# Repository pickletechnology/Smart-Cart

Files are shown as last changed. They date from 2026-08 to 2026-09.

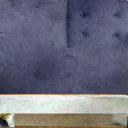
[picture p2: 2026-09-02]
labsim/assets/office2/conference_chair_blue.png

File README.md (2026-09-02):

# Smart Cart

An instrumented physics cart. An ESP32 reads acceleration, force, and wheel
rotation, and streams the combined state over Bluetooth LE to the Physics Cart
app at 20 Hz.

**Current version: V1** — the first complete build. Firmware and 3D-printable
hardware in this repository are all tagged `V1`.

## What's here

```
Smart-Cart/
├── firmware/
│   ├── README.md                       Board, libraries, flashing
│   └── PhysicsCart_V1/
│       └── PhysicsCart_V1.ino          Complete cart firmware
├── hardware/
│   ├── README.md                       Parts list and print settings
│   └── stl/
│       ├── Cart_Casing_8mm_Bearing_V1.stl   Main chassis      ×1
│       ├── Wheel_8mm_Bearing_V1.stl         Wheel             ×4
│       ├── Bearing_Casing_8mm_V1.stl        Bearing housing   ×4
│       └── Axle_8mm_V1.stl                  Axle              ×2
├── simulation/
│   ├── README.md                       Physics model and lab exercises
│   └── index.html                      Smart Cart Lab — browser simulation
├── game/
│   ├── README.md                       Game guide, assets, content pipeline
│   └── index.html                      Cart Blanche — physics adventure game
├── labsim/
│   ├── README.md                       Lab design, grading, assets
│   └── index.html                      The Physics Company — AP lab career
└── docs/
    ├── WIRING.md                       Pinout and sensor connections
    ├── CALIBRATION.md                  Every tunable constant, and how to set it
    └── BLE_PROTOCOL.md                 Service UUIDs and JSON payload format
```

## Simulation

[`simulation/index.html`](simulation/index.html) is **Smart Cart Lab**, a
browser-based 3D simulation of this cart for physics labs — open it in any
modern browser, no install or internet needed. Students run the classic
experiments (hanging mass, inclined track, fan force, bumper collisions,
friction) with live velocity/acceleration/force graphs, and the simulated
cart streams the same 20 Hz JSON lines as the real firmware, so a BLE client
can be developed against it before touching hardware. See
[`simulation/README.md`](simulation/README.md) for the physics model.

## Game

[`game/index.html`](game/index.html) is **Cart Blanche**, a physics adventure
game where the Smart Cart fights the Stationary Front across four worlds of
missions, kinetic-energy combat, and question gates — with XP levels, a shop,
and everything running on the same honest F = ma physics. Open it in any
browser; see [`game/README.md`](game/README.md).

## Lab career game

[`labsim/index.html`](labsim/index.html) is **The Physics Company**, an
AP® Physics 1 lab-career game: hired to certify the SC-01, students run six
real experiments (kinematics through rotation), read their own recorded
telemetry, and type numeric answers with units — checked against their run
within ±4%. Sensors are purchasable upgrades that unlock telemetry, labs pay
per verified answer, and a printable certification transcript records it all.
See [`labsim/README.md`](labsim/README.md).

## Hardware

| Component | Role | Interface |
|---|---|---|
| ESP32 | Controller, BLE peripheral | — |
| MPU-6050 | 3-axis accelerometer + gyroscope | I²C `0x68` |
| AS5600 | Magnetic rotary encoder (wheel angle / speed) | I²C `0x36` |
| HX711 + load cell | Force measurement | GPIO 19 (DOUT) / 18 (SCK) |

All printed parts are built around 8 mm bore bearings. Full pinout in
[`docs/WIRING.md`](docs/WIRING.md).

## Getting started

1. **Print the parts** — [`hardware/README.md`](hardware/README.md). Start with
   the axles and bearing casings to check your printer's tolerance against the
   8 mm bearings.
2. **Wire the electronics** — [`docs/WIRING.md`](docs/WIRING.md). Confirm both
   I²C devices appear on a scanner sketch before flashing.
3. **Flash the firmware** — [`firmware/README.md`](firmware/README.md).
4. **Calibrate** — [`docs/CALIBRATION.md`](docs/CALIBRATION.md). Do not skip
   this; two V1 constants ship with placeholder values.
5. **Connect** — the cart advertises as `PASCO_Cart`. Pair from the Physics Cart
   app, or write your own client against
   [`docs/BLE_PROTOCOL.md`](docs/BLE_PROTOCOL.md).

## Data output

20 Hz JSON notifications over BLE:

```json
{"t":12.34,"ax":0.012,"ay":-0.003,"az":0.998,"gx":0.1,"gy":-0.2,"gz":0.0,"f":0.482,"a":180.5,"r":42.3,"v":0.144}
```

Time (s), acceleration (g), angular rate (°/s), force (N), wheel angle (°),
wheel speed (RPM), and linear velocity (m/s).

## Known V1 issues

These are carried forward from the working build and left as-is in V1 so the
code in this repo matches the cart that was actually running. Each is worth
addressing in the next revision:

- **`WHEEL_DIAMETER_M` is 0.065 m, but the V1 wheel STL is 34 mm across.**
  Velocity scales directly with this constant, so it must be set to the wheel
  you actually built before velocity readings mean anything.
- **`FORCE_OFFSET` is 5396.799 N** and is added on top of the automatic
  boot-time `tare()`. It looks like a leftover from an earlier calibration run —
  `0.0` is the sensible default for a fresh build.
- **No serial output.** The header comment advertises Serial Monitor output, but
  the sketch never calls `Serial.begin()`. BLE is the only output in V1.
- **IMU offsets are all zero** — they are placeholders awaiting a real
  still-cart calibration run.

## Versioning

`V1` marks the first complete cart: firmware, chassis, wheels, bearing casings,
and axles as built. Future revisions get their own `V2` files rather than
overwriting these, so a printed cart can always be matched back to the firmware
it was built with.

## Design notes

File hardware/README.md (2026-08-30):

# Hardware — Smart Cart V1

3D-printable parts for the V1 physics cart. All models are binary STL, dimensioned
in millimetres, and built around **8 mm bore bearings**.

## Parts list

| File | Part | Bounding box (mm) | Triangles | Qty per cart |
|---|---|---|---|---|
| `stl/Cart_Casing_8mm_Bearing_V1.stl` | Main cart chassis / body | 165.0 × 31.8 × 90.0 | 11,164 | 1 |
| `stl/Wheel_8mm_Bearing_V1.stl` | Wheel with bearing seat | 34.0 × 13.3 × 34.0 | 1,192 | 4 |
| `stl/Bearing_Casing_8mm_V1.stl` | Bearing housing / retainer | 16.0 × 6.5 × 8.2 | 876 | 4 |
| `stl/Axle_8mm_V1.stl` | Axle | 4.5 × 41.6 × 4.5 | 842 | 2 |

## Non-printed hardware

- 8 mm bore ball bearings (one per wheel seat)
- Fasteners to suit the chassis mounting holes

## Suggested print settings

These are starting points, not measured-and-proven values — tune for your printer.

| Setting | Chassis | Wheels / bearing casings / axles |
|---|---|---|
| Material | PLA or PETG | PLA or PETG |
| Layer height | 0.20 mm | 0.16 mm |
| Walls | 3 | 3–4 |
| Infill | 20–25 % | 40 % |
| Supports | Only where overhangs require | Usually none |

Print the axles and bearing casings first — they are quick, and they confirm your
printer's tolerance against the 8 mm bearings before you commit to the ~4 hour
chassis print.

## Wheel diameter and the firmware

The V1 wheel STL measures **34 mm** across. The firmware's `WHEEL_DIAMETER_M`
constant currently reads `0.065` (65 mm). Velocity is derived from wheel
circumference, so this constant must match the wheel that is actually on the
cart — measure your printed-and-assembled wheel (including any tyre or grip
surface) and set it before trusting velocity data. See
[`../docs/CALIBRATION.md`](../docs/CALIBRATION.md).

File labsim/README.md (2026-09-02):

# The Physics Company

*Making Motion Happen™* — an AP® Physics 1 lab-career game built on the Smart
Cart simulation. You've been hired by The Physics Company's Field Test Division
to certify the **SC-01 Smart Cart** through seven laboratory evaluations. Run
the experiments, read **your own** recorded data, and type numeric answers
(with units) that are checked against that data.

**Run it:** open `labsim/index.html` in any browser — fully offline, all assets
embedded. Enter your name at hiring (it goes on your printable transcript).

## The shape of a day

- **Title screen** over a living city street (traffic, pedestrians, the TPC
  building), then a skippable **cinematic intro**: your character drives in,
  parks, walks to the front door — and sits down with **R. Fulcrum, Founder &
  Owner**, who explains exactly what you've signed up for (click / Space
  through the dialogue).
- **The lab floor is walkable** (WASD/arrows or click-to-walk, E to use):
  a test bench where the labs run, a workshop desk where the SC-01 gets
  modified, a mail terminal for Marla's memos (many take **replies** — pick
  one, she answers), an equipment wall, the Deep End tank, a records desk with
  your transcript, Engineer #7's taped-off desk… and your cot.
- **Bench setup, PC-Building-Simulator style**: every lab starts with a parts
  tray — click a part, click its glowing spot; **right-click a placed part**
  to take it back. **Drag to orbit the bench, scroll to zoom**; while setting
  up, the camera frames the whole track so every slot is in reach. Cart on
  the track, pulley clamped past the 10 m mark, hanging mass over the pulley,
  spring bumper, Cart B, the Deep End's tank/boom/test cylinder. Nothing runs
  until the bench is built, and Lab 01 walks first-timers through it step by
  step.
- **After each certified lab you clock out**: a night-time sleep cutscene ends
  the day (DAY N COMPLETE), the day counter and your clearance level tick up —
  and the lab wakes up a little more lived-in: coffee cups, takeout cartons
  and pizza boxes accumulate with every certification.
- **Engineer #7's notes are physical**: after each lab, one turns up somewhere
  on the lab floor. Walk to the glow and read it where it fell.

## How learning works here

- **Seven labs, one per AP Physics 1 unit** (fluids included, per the 2024+
  curriculum), each an in-depth multi-part worksheet (5 calculations + 1
  concept question, labeled like AP parts):
  1. **Kinematics** — Baseline Certification (position/time tables, x = ½at²;
     the boost pass is a hanging mass over the end pulley)
  2. **Dynamics & friction** — The Grip Department (μs = tan θ from a tilt
     test; μk from measured a on an incline; three real surfaces)
  3. **Energy** — The Conservation Audit (outdoor mountain range; mgh → ½mv²;
     % difference; work–energy on a gravel patch)
  4. **Momentum** — Impact Assessment (load-cell impulse ∫F dt vs Δp; elastic
     and perfectly inelastic collisions with Cart B)
  5. **Simple harmonic motion** — Resonance Division (period from zero
     crossings; k = 4π²m/T²; prediction with added mass)
  6. **Rotation** — The Spin Cycle (ω from real RPM; v = ωr; α; rolling
     without slipping)
  7. **Fluids** — The Deep End (weigh a test cylinder in air, submerge it on
     the load-cell winch; F_b = F_air − F_sub; ρ = F_b/Vg for water and brine
     from the student's own readings)
- **Answers are numeric + unit**, checked against the student's own run within
  ±4% (unit must be right too). Pay decays 100% → 70% → 40%: after two misses
  the worked solution appears, but the student must still enter the correct
  value to proceed. Nobody gets stuck; guessing still costs.
- **Experiment parameters are randomized per session** (friction coefficients,
  spring constants), so answers can't be shared — only methods can.
- **Sensors are upgrades**: the cart starts with just position (ruler +
  stopwatch). Buying the real V1 hardware unlocks capability — the AS5600
  encoder unlocks velocity telemetry, the MPU-6050 acceleration, the HX711
  load cell force/impulse — and each is required by a later lab (stipends in
  the story keep them affordable).
- **The transcript** (HQ → Transcript) is a printable/saveable certification
  record: name, hire date, per-lab score, attempt counts, and pay — evidence a
  teacher can check.

## The story

Corporate comedy with a mystery, told interactively: memos from Marla Joule
(Director of Cart Reliability, extremely fast in hallways — watch the
sidewalk) assign each lab and take replies; HR sends automated warnings about
naming company property; and physical notes from vanished Test Engineer #7
turn up on the lab floor after each certification… ending with a message from
the SC-01 itself (which also takes a reply). Days pass, clearance levels rise,
takeout accumulates, certificates fill the wall, and cosmetic upgrades
(shells, LED colors, accessories, office furniture) make your corner of the
company visibly yours. The finale is a warm one — listen to the LED.

## Assets

- **KayKit Block Bits**, **KayKit Furniture Bits**, and **KayKit City Bits**
  by Kay Lousberg (kaylousberg.com), CC0 — test-chamber blocks, surfaces
  (metal/sand/frost/gravel), furniture, and the city street, buildings and
  cars. Licenses in `assets/*/LICENSE.txt`.
- **OFFICE** low-poly pack (user-provided, converted from `.glb` via
  `tools/convert-glb.mjs`) — desks, chairs, computers, cabinets, coffee
  machine, water cooler and friends.
- **MountainRocks** voxel pack (user-provided) — the outdoor test range.
- The SC-01 itself is procedural, with sensor modules that visibly bolt on as
  you buy them; the characters (you, Marla, pedestrians) are procedural
  low-poly walkers.

`tools/build-assets.mjs` parses everything under `assets/` into compact mesh
data embedded between the `/*ASSETS_START*/` markers — drop in new `.obj`
files (with `atlas.png` for shared-atlas packs, or per-model `.png`) and
re-run it.

## Engine notes

Physics integrates at 240 Hz per lab-specific force model; telemetry records
at 60 Hz into the data table (0.5 s rows), charts, and an events line (slip
angle, impulse, contact time, zero crossings…). Question generators compute
accepted answers from the same recorded arrays the student reads, so the
numbers always agree with the screen. AP® is a trademark of the College
Board, which was not involved in and does not endorse this project.

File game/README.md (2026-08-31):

# Cart Blanche — the Smart Cart video game

*Physics, floor it.*

A single-file HTML5 physics adventure game starring **Newt**, a self-aware
Smart Cart, versus the **Stationary Front** — a union of grumpy lab equipment
sworn to bring all motion to a stop. Everything in the game runs on honest
physics, and every fight, gate, and upgrade teaches some of it.

**Run it:** open `game/index.html` in any modern browser. Fully offline —
Three.js and all 3D assets are embedded/vendored. Keyboard: ◀ ▶ thrust,
▼ brake, Esc pause, R restart. Touch controls appear on mobile.

## What's in the game

- **A walkable campus hub**: you play a lab tech on foot (WASD / drag to
  walk, Shift to run, E to interact) exploring a large open campus with
  Newt trundling along behind you. Four world portals, NPCs with physics
  gossip, Millie Volt's shop as a real building, and one-time collectible
  coins are scattered across the map. Menus (Missions/Shop buttons) remain
  as fast travel.
- **4 worlds × 5 missions** (20 total), each world tied to a physics topic:
  *Vector Valley* (kinematics), *Grindstone Gulch* (friction & inclines),
  *The Conservatory* (energy), *The Colliseum* (momentum) — each ending in a
  boss fight (Delta Vee, Big Mu, Grand Dame Potentia, General Standstill).
- **Real physics engine** (120 Hz): F = ma along the slope, gravity g·sinθ
  on hills, rolling friction, quadratic drag, ballistic flight off crests,
  mud (μ×14) and ice (μ×0.1) zones. The HUD telemetry strip — velocity,
  acceleration, force, kinetic energy — is the same set of quantities the
  real Smart Cart streams over BLE.
- **PVE with kinetic-energy combat**: every enemy wears its KE threshold in
  joules; you destroy it only if your live ½mv² beats that number when you
  ram, otherwise you bounce and lose battery. Turrets lob real parabolic
  projectiles. Bosses take multiple hits and enrage.
- **Question gates**: 48 multiple-choice physics questions (12 per topic,
  each bank independently re-derived and corrected by a verifier pass)
  block checkpoints; correct answers pay points, XP, and battery — and
  stack an **Overvolt streak** (+1 N thrust per first-try answer, up to
  +3 N, lost on a wrong answer). A **LETHAL glow** on the KE readout shows
  when your kinetic energy currently beats a nearby enemy's threshold.
- **Points, stars, and par scores** per mission; battery and time convert
  to bonus points at the finish.
- **Leveling**: XP from missions and questions; levels + beaten bosses
  unlock the next world.
- **Shop**: spend Joulies with Millie Volt on a stronger motor (thrust),
  slicker bearings (lower μ), a bigger battery (more health, but heavier —
  trade-offs are physics too), an impulse-damper shield, a coin magnet,
  and cosmetic car bodies.
- **Mission types**: reach, coin-collect, speed-window finishes, battles,
  and boss fights, over six procedural terrain profiles (seeded per mission,
  so a mission's track is always the same).
- Saves in `localStorage` (per browser). "Reset save" on the title screen.

## Assets

- **KayKit City Builder Bits 1.0** by Kay Lousberg (kaylousberg.com) — CC0.
  Buildings, cars (the player cart and several enemies/skins), streetlights,
  traffic lights, props. License copy in `assets/kaykit/LICENSE.txt`.
- **MagicaVoxel building models** (`assets/voxel/`) — uploaded pack of six
  voxel buildings used as skyline decoration.
- Everything else (terrain, gates, coins, effects, extra props) is generated
  procedurally in code.

### Asset pipeline

`tools/build-assets.mjs` parses every `.obj` under `assets/` into compact
quantized mesh data (positions ×1000, UVs ×10000, indexed, with bounding
boxes), base64-encodes the textures, and splices the result into
`index.html` between the `/*ASSETS_START*/ … /*ASSETS_END*/` markers.
To add more assets: drop `.obj` (+ texture) files into `assets/kaykit/`
(shared atlas) or `assets/voxel/` (per-model texture), run
`node game/tools/build-assets.mjs`, and reference the new mesh names in
`WORLD_ART`/`extraProp` in `index.html`.

## Content pipeline

The theme, mission set, enemy roster, shop economy, and question banks were
generated as structured JSON by a multi-agent workflow (three competing
creative directions judged and synthesized; question banks written per topic
then adversarially re-derived by an independent checker) and embedded at the
`/*__GAME_DATA__*/` marker. The game reads everything from that `DATA`
constant, so content can be regenerated or hand-edited without touching the
engine.

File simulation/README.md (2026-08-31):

# Smart Cart Lab — Physics Simulation

A browser-based simulation of the Smart Cart V1 for physics labs. Students set
up the same experiments they would run with the real cart — a hanging mass over
a pulley, an inclined track, a fan force, a collision with a spring bumper —
and read the same quantities the real hardware reports, in the same format.

**Run it:** open `index.html` in any modern browser. No build step, no server,
no internet connection required (Three.js is vendored in `vendor/`).

```
simulation/
├── index.html          The whole application (UI, physics, rendering)
├── vendor/
│   └── three.min.js    Three.js r128 (MIT), vendored for offline lab use
└── README.md           This file
```

## What it simulates

The apparatus is a track on a lab table, with:

| Element | Parameter | Range |
|---|---|---|
| Track length | table and camera resize with it | 0.60–2.00 m |
| Track incline | pivots at the pulley end, far end rises | 0–20° |
| Cart | mass (V1 printed cart ≈ 250 g default) | 150–1500 g |
| Hanging mass | string over an end pulley, classic modified Atwood | 0–300 g |
| Fan force | constant thrust along the track | ±1 N |
| Friction | single coefficient, kinetic + static (μₛ = 1.15 μₖ) | 0–0.30 |
| Spring bumper | at the pulley end, 900 N/m, tunable elasticity | 30–100 % |
| Initial push | initial velocity applied at t = 0 | ±1.2 m/s |

Five presets set these up as the classic experiments (Newton's second law,
inclined release, fan cart, bumper collision, static friction hold); every
slider stays live for custom setups.

### Equations of motion

Let `x` be the cart's distance from the pulley along the track and θ the
incline (the pulley end is the low end). With cart mass *m꜀*, hanging mass
*mₕ* and normal force *N = m꜀g cos θ*:

- **String taut** (coupled system, tension cannot be negative):
  `(m꜀ + mₕ) ẍ = F_fan + F_bumper − m꜀g sin θ − mₕg ∓ μₖN`
  and the tension the force sensor reads is `T = mₕ(g + ẍ)`.
- **String slack / no hanging mass:** the cart moves alone and the mass
  free-falls. When the cart re-tensions the string, the snap is resolved by
  momentum conservation along the string (both bodies jump to the common
  constraint velocity), and the jolt shows up on the simulated IMU.
- **Mass lands:** when the hanging mass reaches the floor the string goes
  slack — the classic "acceleration stops mid-run" feature of this lab.
- **Static friction** holds the cart whenever it is at rest and the net
  driving force is below μₛN (so a cart on a shallow incline genuinely
  does not move until tan θ exceeds μₛ).
- **Bumper:** a damped spring (`F = kΔx − cẋ`, k = 900 N/m); the damping
  is derived from the elasticity slider, and the contact force is what the
  hook force sensor reports (negative = compression), so students can see
  that a collision is a brief, large force and measure the impulse.

Integration is semi-implicit Euler at 240 Hz — four physics substeps per
sensor sample, so collisions and string snaps are resolved well below the
sensor timescale.

### The sensor pipeline mirrors the V1 firmware

The point of the app is that students practice on *instrument readings*, not
on idealized values, so the measurement chain from
`firmware/PhysicsCart_V1/PhysicsCart_V1.ino` is reproduced:

- Sensors sample at **60 Hz**; the BLE JSON line is emitted at **20 Hz** in
  the exact `snprintf` format and precision of the firmware
  (`{"t":…,"ax":…,…,"v":…}` — see `docs/BLE_PROTOCOL.md`).
- **IMU (MPU-6050):** reports *specific force* in g, so `az ≈ cos θ` at rest
  (≈ +1 g on the level — the firmware's calibration check) and `ax ≈ 0`
  during frictionless free roll, because an accelerometer measures proper
  acceleration. Bumper impacts ring the chassis at ~42 Hz. The cart's IMU
  x-axis points toward the pulley, matching how the cart is set on the track.
- **Wheel encoder (AS5600):** wheel angle wraps 0–360°, RPM goes through the
  firmware's 5-sample moving average and is forced to zero below 2 RPM, and
  reported velocity is `(RPM / 60) × π × d` — with **d = 34 mm**, the size the
  V1 wheel actually prints at (see "Known V1 issues" in the root README).
- **Load cell (HX711):** reads the hook — string tension positive, bumper
  compression negative, `FORCE_OFFSET = 0` (a freshly calibrated cart).
- **Noise toggle:** Gaussian sensor noise at realistic levels
  (σ ≈ 3 mg accel, 0.15 °/s gyro, 15 mN force, 0.8 RPM encoder jitter).
  Switch it off to compare against clean theory.

### Displays

- Live readout tiles: position, velocity, acceleration, hook force, wheel
  RPM, and the IMU's `az` (the "is the cart level?" sanity check).
- Three strip charts (10 s window): velocity, acceleration, hook force —
  plotting what the *sensors* report, like real DAQ software.
- A **BLE Notify console** streaming the exact 20 Hz JSON lines, so students
  can develop and test a client against `docs/BLE_PROTOCOL.md` behavior
  before touching hardware.
- **CSV export** (download or copy): 60 Hz samples with both the sensor
  readings and the true kinematic values side by side, for analysis in a
  spreadsheet — comparing the two *is* a good lab exercise.

### Rendering

Three.js with physically-based materials, one warm key light casting soft
shadows (2048² PCF), a cool hemisphere sky term for ambient, and ACES filmic
tone mapping. Scene units are metres and the geometry matches the build: a
34 mm wheel is a 34 mm wheel on screen.

## Suggested lab exercises

1. **Newton's second law** — vary the hanging mass, measure the slope of the
   velocity trace, compare with `a = mₕg / (m꜀ + mₕ)`. Explain the kink in
   the trace when the mass hits the floor.
2. **g from an incline** — release from rest at several angles, plot `a`
   against `sin θ`, extract g from the slope and μ from the intercept.
3. **Proper acceleration** — explain why `ax` reads ≈ 0 while the cart rolls
   freely downhill but `−sin θ` when it is held still.
4. **Impulse–momentum** — integrate the force spike of a bumper collision
   (export CSV) and compare with the measured Δv, at several elasticities.
5. **Static vs kinetic friction** — with μ = 0.15, raise the incline slowly
   until the cart breaks away; compare the break-away angle with arctan μₛ.

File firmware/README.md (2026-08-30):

# Firmware — Smart Cart V1

`PhysicsCart_V1/PhysicsCart_V1.ino` — the complete cart firmware. Reads the
MPU-6050, HX711 load cell, and AS5600 encoder, and streams the combined state
over BLE as JSON.

## Board

ESP32 (any dev board with BLE). Select it in **Tools → Board** before compiling;
the sketch uses the ESP32 BLE stack (`BLEDevice.h` and friends), which ships with
the ESP32 Arduino core.

## Library dependencies

Install through **Sketch → Include Library → Manage Libraries…**:

| Library | Used for |
|---|---|
| `HX711` (bogde) | Load cell amplifier |
| `AS5600` (RobTillaart) | Magnetic rotary encoder |

`Wire.h` and the `BLE*` headers come from the ESP32 core — nothing to install.

## Flashing

1. Install the ESP32 board support package (Boards Manager URL:
   `https://raw.githubusercontent.com/espressif/arduino-esp32/gh-pages/package_esp32_index.json`).
2. Open `PhysicsCart_V1/PhysicsCart_V1.ino`. The folder name must keep matching
   the sketch name — Arduino requires it.
3. Select your ESP32 board and port, then Upload.

## Loop timing

| Task | Rate | Constant |
|---|---|---|
| Sensor sampling | 60 Hz | `SENSOR_INTERVAL_US = 16667` |
| BLE notification | 20 Hz | `BLE_INTERVAL_MS = 50` |

## Before you trust the data

Work through [`../docs/CALIBRATION.md`](../docs/CALIBRATION.md). Two constants in
particular ship with values that will not be right for your build:
`WHEEL_DIAMETER_M` (65 mm, against a 34 mm V1 wheel STL) and `FORCE_OFFSET`
(5396.799 N, on top of an automatic boot-time tare).

## Output

BLE JSON at 20 Hz — see [`../docs/BLE_PROTOCOL.md`](../docs/BLE_PROTOCOL.md) for
the field-by-field payload description.

Note that the header comment mentions Serial Monitor output, but this version
does not call `Serial.begin()` or print anything. BLE is the only output path in
V1. Adding serial logging is a natural V1.1 change.

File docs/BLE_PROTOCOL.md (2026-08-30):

# BLE Protocol — Smart Cart V1

## Advertising

| Property | Value |
|---|---|
| Device name | `PASCO_Cart` |
| Service UUID | `4fafc201-1fb5-459e-8fcc-c5c9c331914b` |
| Characteristic UUID | `beb5483e-36e1-4688-b7f5-ea07361b26a8` |
| Characteristic properties | `READ`, `NOTIFY` (with a `0x2902` CCCD descriptor) |

The name `PASCO_Cart` is what the Physics Cart app scans for — changing it in the
firmware means the app will no longer find the cart.

## Data flow

- Sensors are sampled at **60 Hz** (`SENSOR_INTERVAL_US = 16667`).
- Notifications are sent at **20 Hz** (`BLE_INTERVAL_MS = 50`), only while a
  central is connected.
- On disconnect the firmware waits 500 ms and restarts advertising, so a client
  can reconnect without power-cycling the cart.

## Payload

Each notification is a UTF-8 JSON object, written into a 220-byte buffer:

```json
{"t":12.34,"ax":0.012,"ay":-0.003,"az":0.998,"gx":0.1,"gy":-0.2,"gz":0.0,"f":5396.799,"a":180.5,"r":42.3,"v":0.144}
```

| Key | Quantity | Unit | Notes |
|---|---|---|---|
| `t` | Time since boot | s | 2 decimal places |
| `ax` | Acceleration X | g | ±2 g range (16384 LSB/g) |
| `ay` | Acceleration Y | g | |
| `az` | Acceleration Z | g | Not offset-corrected — carries the 1 g gravity term |
| `gx` | Angular rate X | °/s | ±250 °/s range (131 LSB/°/s) |
| `gy` | Angular rate Y | °/s | |
| `gz` | Angular rate Z | °/s | |
| `f` | Force | N | Load cell, includes `FORCE_OFFSET` |
| `a` | Wheel angle | ° | AS5600, 0–360 |
| `r` | Wheel speed | RPM | 5-sample moving average; forced to 0 below 2 RPM |
| `v` | Linear velocity | m/s | Derived: `(RPM / 60) × wheel circumference` |

Acceleration is reported in **g**, not m/s² — multiply by 9.81 on the client if
you want SI units.

## Writing a client

1. Scan for `PASCO_Cart` or filter on the service UUID.
2. Connect, discover the service, and subscribe to notifications on the
   characteristic (write `0x0001` to its CCCD).
3. Parse each notification as JSON. Expect ~20 messages per second.

There are no writable characteristics in V1 — the cart is send-only. Taring,
calibration, and zeroing all happen in firmware at boot.

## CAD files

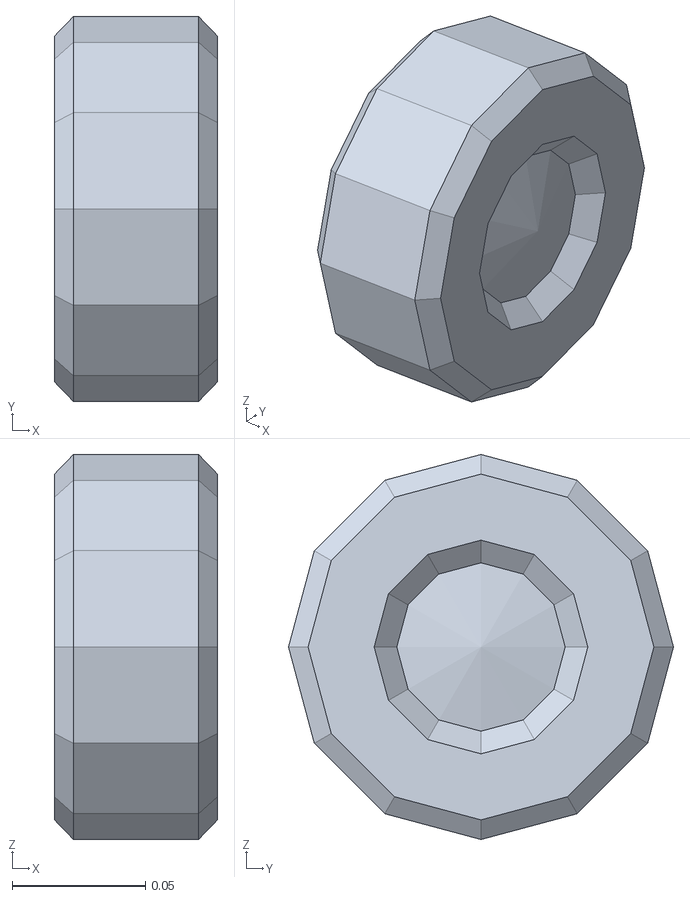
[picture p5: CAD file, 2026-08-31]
game/assets/kaykit/car_taxi_wheel_rear_left.obj
0.0612 x 0.145 x 0.145

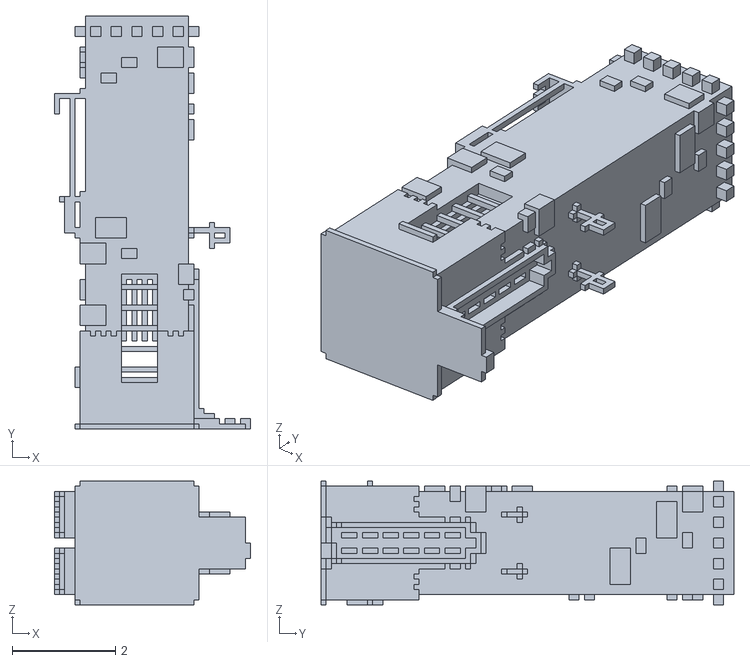
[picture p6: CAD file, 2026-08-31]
game/assets/voxel/TallBuilding03.obj
3.80 x 8.00 x 2.40

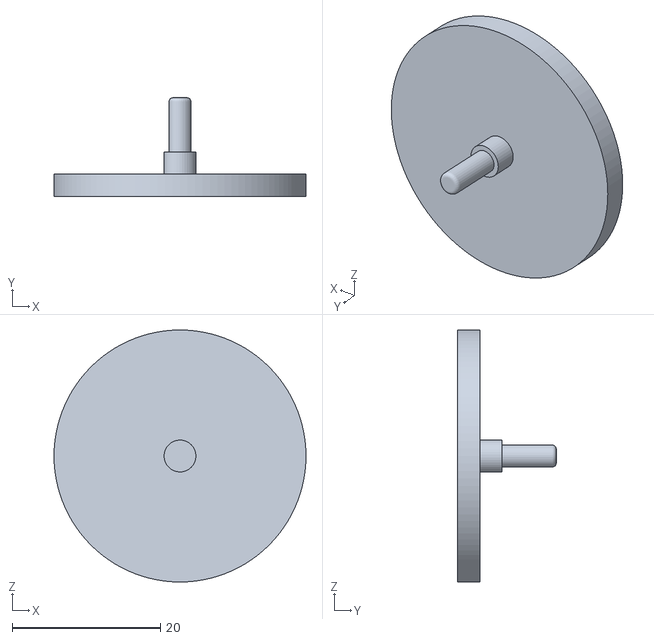
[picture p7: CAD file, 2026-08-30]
hardware/stl/Wheel_8mm_Bearing_V1.stl
34.0 x 13.3 x 34.0

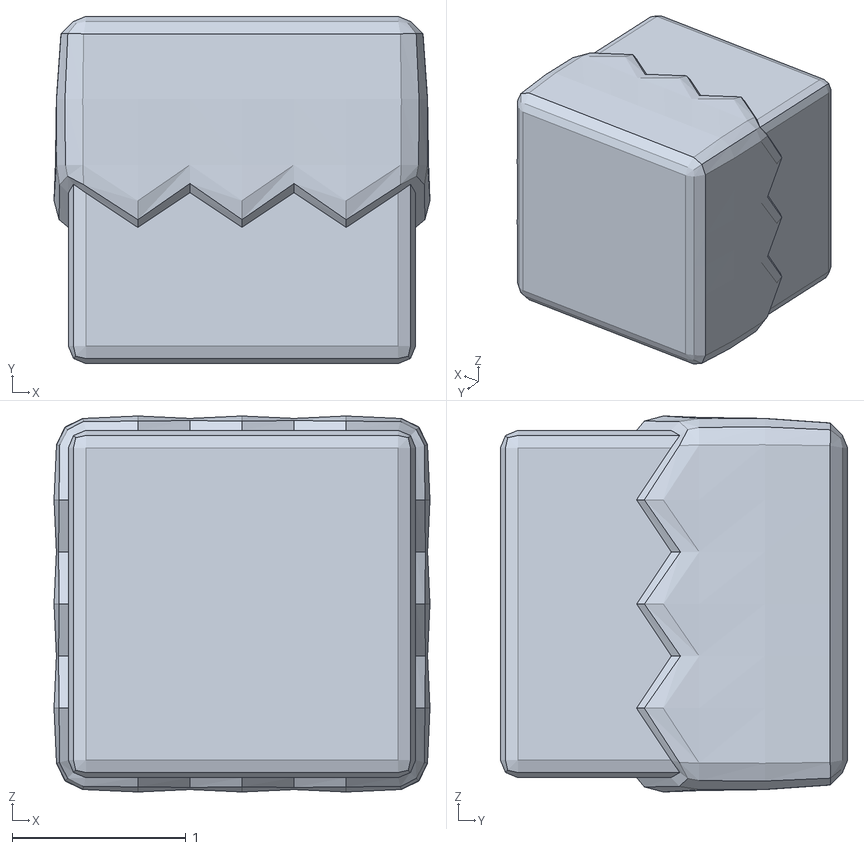
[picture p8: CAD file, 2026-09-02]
labsim/assets/blockbits/tree.obj
2.17 x 2.00 x 2.17

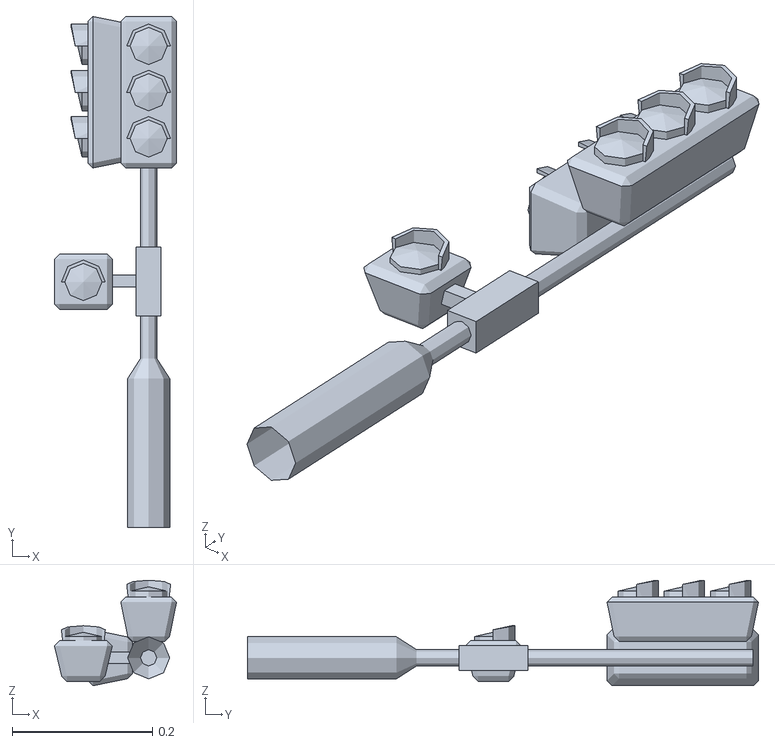
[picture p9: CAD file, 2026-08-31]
labsim/assets/city/trafficlight_A.obj
0.174 x 0.729 x 0.151

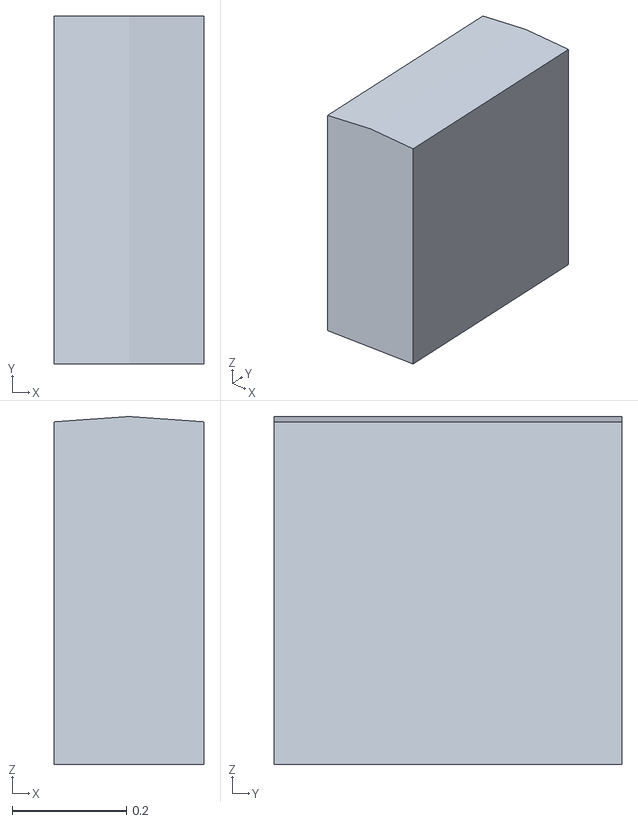
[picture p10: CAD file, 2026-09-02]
labsim/assets/computer/computer_tower.obj
0.262 x 0.609 x 0.609

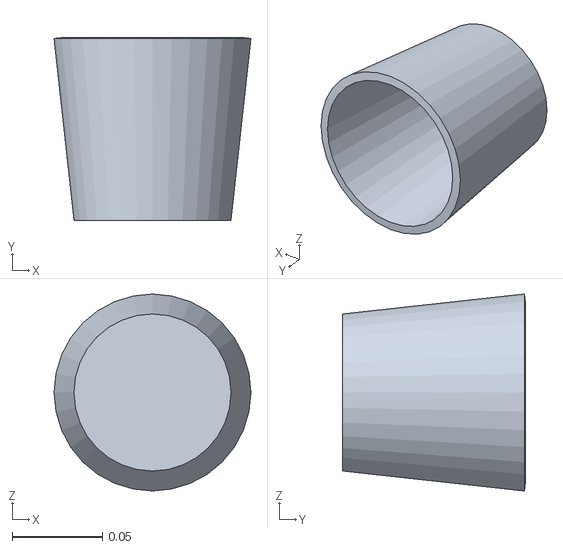
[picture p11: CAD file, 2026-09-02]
labsim/assets/deskpack/pencil_holder.obj
0.109 x 0.102 x 0.109

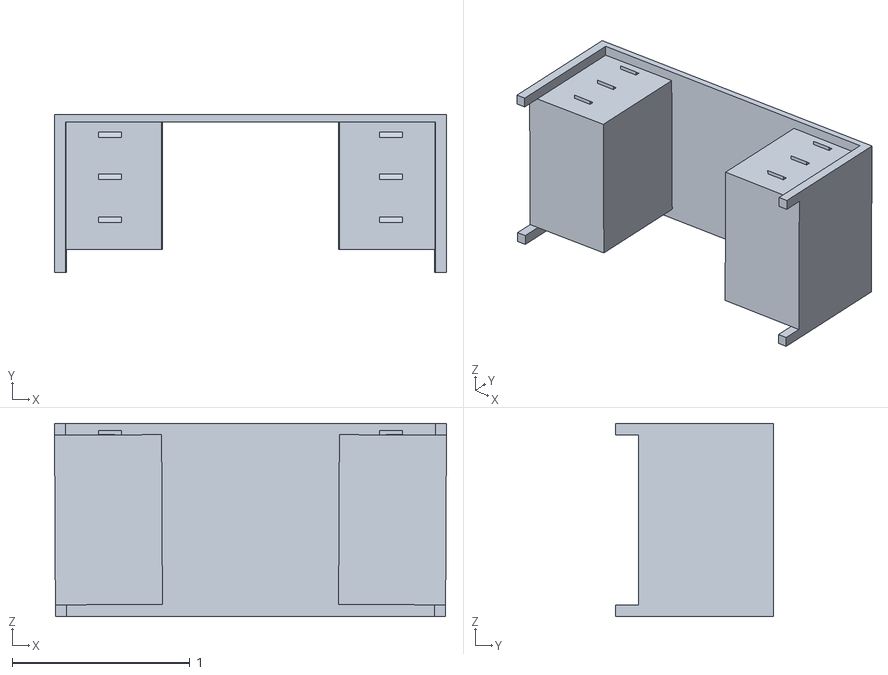
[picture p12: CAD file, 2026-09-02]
labsim/assets/desks1/desk1.obj
2.21 x 0.891 x 1.09

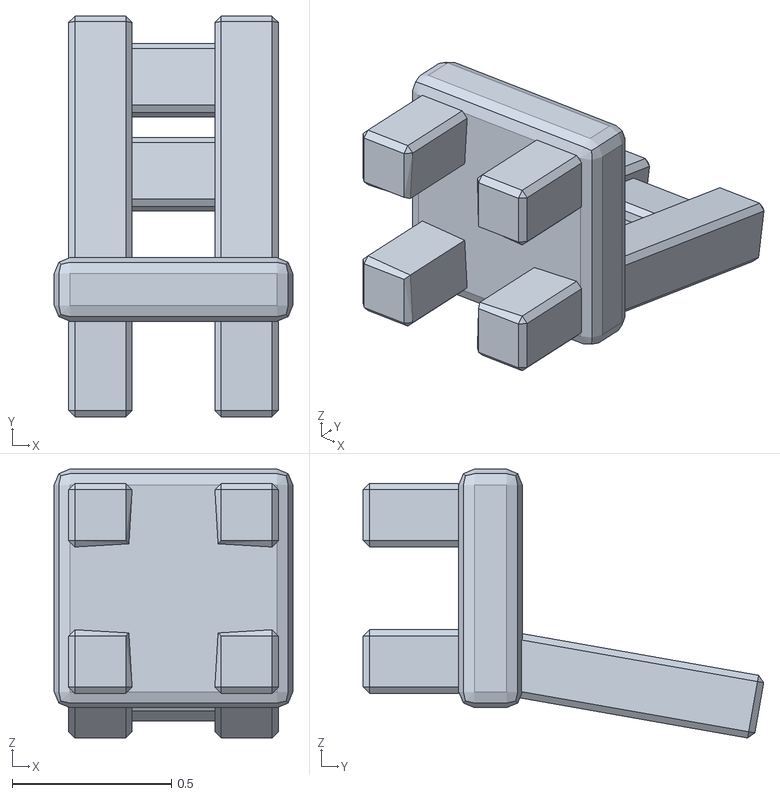
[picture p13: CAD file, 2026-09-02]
labsim/assets/furniture/chair_A.obj
0.75 x 1.26 x 0.845

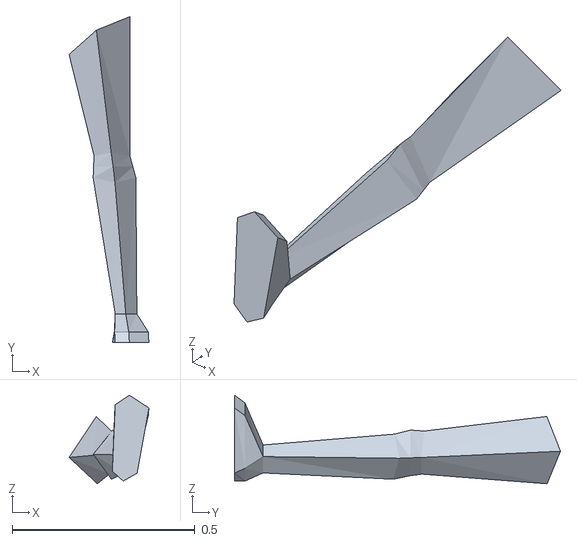
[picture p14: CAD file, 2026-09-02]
labsim/assets/human/h_legR.obj
0.219 x 0.893 x 0.243

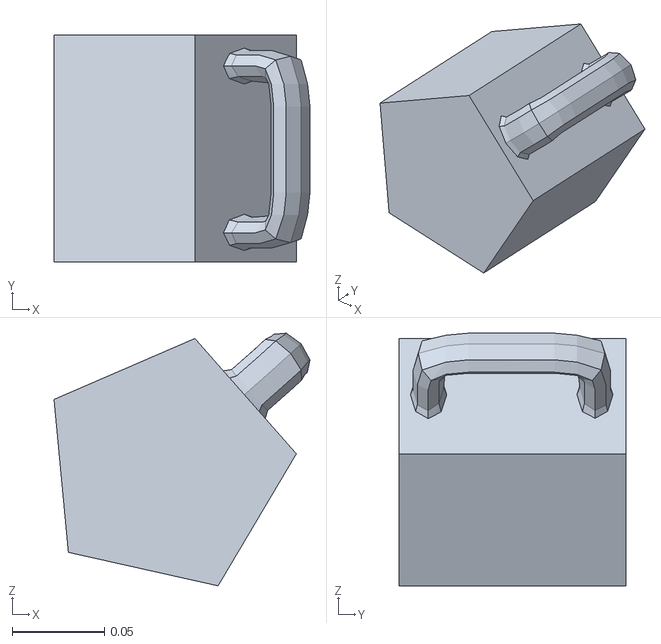
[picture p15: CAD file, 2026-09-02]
labsim/assets/office2/mug.obj
0.139 x 0.123 x 0.137

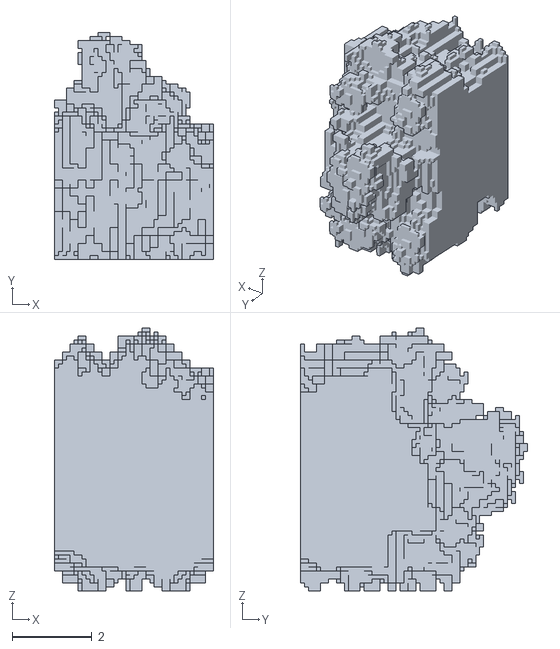
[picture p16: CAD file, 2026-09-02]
labsim/assets/rocks/MountainRocks-5.obj
4.00 x 5.70 x 6.60

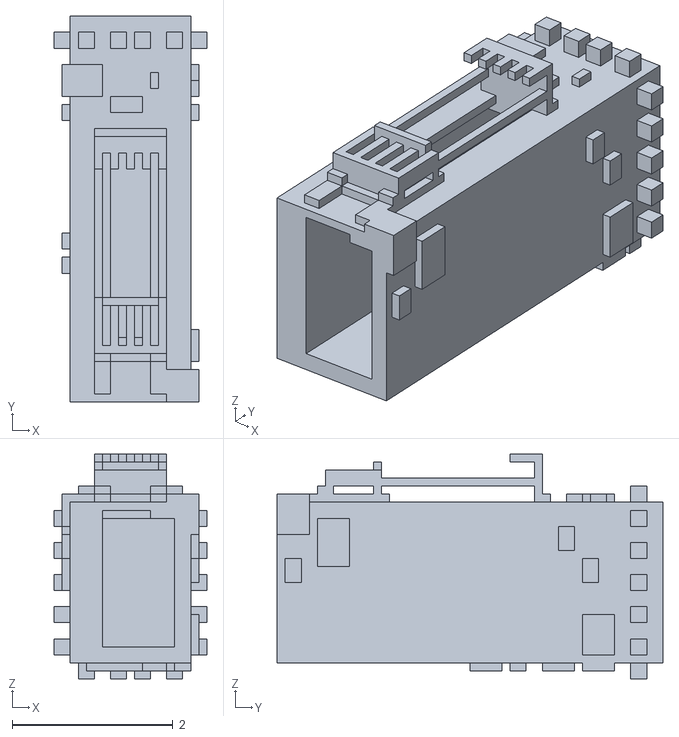
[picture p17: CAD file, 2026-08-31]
game/assets/voxel/TinyBuilding01.obj
1.90 x 4.80 x 2.80

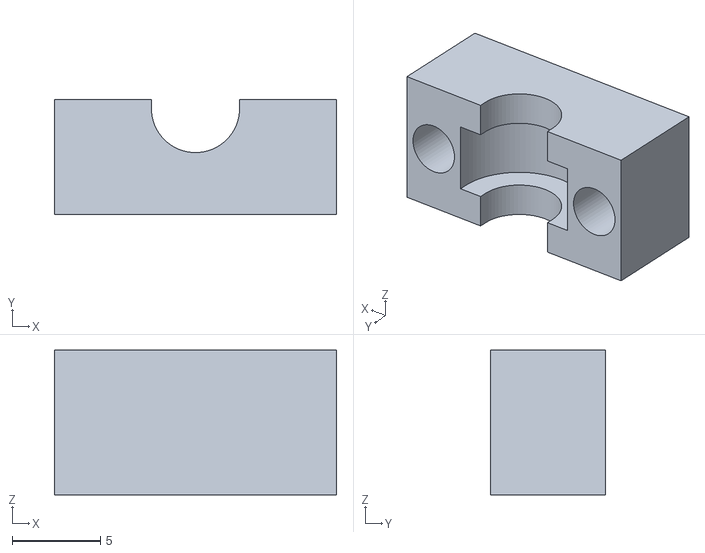
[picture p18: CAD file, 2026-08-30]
hardware/stl/Bearing_Casing_8mm_V1.stl
16.0 x 6.50 x 8.20

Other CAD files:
game/assets/kaykit/car_police_wheel_front_right.obj
labsim/assets/blockbits/colored_block_yellow.obj
labsim/assets/city/road_straight.obj
labsim/assets/computer/computer_keyboard.obj
game/assets/kaykit/box_A.obj
game/assets/kaykit/car_hatchback_wheel_front_left.obj
game/assets/kaykit/car_hatchback_wheel_front_right.obj
game/assets/kaykit/car_hatchback_wheel_rear_left.obj
game/assets/kaykit/car_hatchback_wheel_rear_right.obj
game/assets/kaykit/car_police_wheel_front_left.obj
game/assets/kaykit/car_police_wheel_rear_left.obj
game/assets/kaykit/car_police_wheel_rear_right.obj
game/assets/kaykit/car_stationwagon_wheel_front_left.obj
game/assets/kaykit/car_stationwagon_wheel_front_right.obj
game/assets/kaykit/car_stationwagon_wheel_rear_left.obj
game/assets/kaykit/car_stationwagon_wheel_rear_right.obj
game/assets/kaykit/car_taxi_wheel_front_left.obj
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

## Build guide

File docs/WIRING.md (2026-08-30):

# Wiring — Smart Cart V1

The firmware targets an **ESP32** (BLE + two hardware I²C-capable pins). Pin
assignments below are taken directly from `firmware/PhysicsCart_V1/PhysicsCart_V1.ino`.

## I²C bus (shared)

`Wire.begin(21, 22)` at 400 kHz.

| Signal | ESP32 pin |
|---|---|
| SDA | GPIO 21 |
| SCL | GPIO 22 |

Two devices share this bus:

| Device | Address | Purpose |
|---|---|---|
| MPU-6050 | `0x68` | 3-axis accelerometer + 3-axis gyroscope |
| AS5600 | `0x36` (fixed) | Magnetic rotary encoder — wheel angle and angular speed |

Both need 3.3 V and ground. The AS5600 breakout usually carries its own pull-ups;
if you have pull-ups on both boards the bus may still work, but drop one set if
you see I²C errors.

## HX711 load cell amplifier

| Signal | ESP32 pin |
|---|---|
| DOUT | GPIO 19 |
| SCK  | GPIO 18 |
| VCC  | 3.3 V (or 5 V if your board is 5 V-tolerant on data lines) |
| GND  | GND |

The load cell itself wires to the HX711 in the usual bridge arrangement
(E+/E−/A+/A−). Colour codes vary by cell — check your load cell's datasheet
rather than assuming.

## AS5600 magnet

The AS5600 reads a **diametrically magnetised** magnet mounted on the axle end,
centred over the chip and typically 0.5–3 mm away. `encoder.begin(4)` sets the
direction-control pin to GPIO 4. If your breakout has no DIR pin, tie it as the
board documents; a reversed reading shows up as negative RPM for forward motion.

## Power

Any supply that gives the ESP32 a clean 3.3 V rail. The HX711 is the noise-
sensitive part of this circuit — keep its wiring short, away from motor or
battery leads, and grounded to the same point as the ESP32.

## Quick check

With everything wired and powered, an I²C scanner sketch should report `0x68`
and `0x36`. If either is missing, fix that before flashing the cart firmware.

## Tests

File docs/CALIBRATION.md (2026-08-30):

# Calibration — Smart Cart V1

Every constant here lives at the top of
`firmware/PhysicsCart_V1/PhysicsCart_V1.ino`. Recalibrate after any mechanical
change — a new load cell, a reprinted wheel, a remounted sensor.

## 1. Wheel diameter — `WHEEL_DIAMETER_M`

```cpp
const float WHEEL_DIAMETER_M = 0.065;  // metres
```

Velocity is computed as `(RPM / 60) × π × WHEEL_DIAMETER_M`, so an error here
scales every velocity reading proportionally.

The V1 wheel STL measures **34 mm** (0.034 m) across, while the constant is set
to 65 mm. Measure the wheel you actually printed and assembled — with any tyre,
o-ring, or grip surface fitted, since that is what contacts the track — and set
the constant to that value in metres. Sanity-check by rolling the cart a
measured 1.000 m and confirming the integrated velocity lands near 1 m.

## 2. Load cell — `CALIBRATION_FACTOR`

```cpp
const float CALIBRATION_FACTOR = -33.0;  // raw units per gram
```

1. Flash a sketch that prints `scale.get_units()` with the scale factor set to `1.0`.
2. With nothing on the cell, note the raw reading, then call `tare()`.
3. Place a known mass (a calibration weight, or anything you have measured on an
   accurate scale) and note the new raw reading.
4. `CALIBRATION_FACTOR = (loaded_raw − tared_raw) / known_mass_in_grams`.
5. Keep the sign — negative simply means the cell is wired or loaded in the
   opposite sense, which is fine.

Verify with a second, different mass. The reading should be within a few percent.

## 3. Force zero — `FORCE_OFFSET`

```cpp
const float FORCE_OFFSET = 5396.799;  // newtons
```

This is added to every force reading:
`force_N = (grams / 1000 × 9.81) + FORCE_OFFSET`.

Note that the firmware already calls `scale.tare(20)` at boot, which zeroes the
cell in hardware. A non-zero `FORCE_OFFSET` on top of that shifts every reported
force by a constant — the value above is large enough that it dominates the
signal, so it is almost certainly a leftover from an earlier calibration run.
**Unless you know why you need it, set it to `0.0`.** If you do need an offset,
derive it as the average steady-state force reported with the cart at rest and
unloaded, negated.

## 4. IMU offsets — `ACCEL_*_OFFSET`, `GYRO_*_OFFSET`

```cpp
const float ACCEL_X_OFFSET = 0.0;
const float ACCEL_Y_OFFSET = 0.0;
const float GYRO_X_OFFSET  = 0.0;
const float GYRO_Y_OFFSET  = 0.0;
const float GYRO_Z_OFFSET  = 0.0;
```

With the cart level and completely still, log `ax`, `ay`, `gx`, `gy`, `gz` for
about 10 seconds and average each. Those averages are your offsets — the
firmware subtracts them.

`accelZ` is deliberately **not** offset-corrected: it should read ≈ +1.0 g at
rest, since it carries gravity. Use that as your check that the IMU is level and
scaled correctly.

## 5. Noise floor — `RPM_THRESHOLD` and `NUM_SAMPLES`

```cpp
const float RPM_THRESHOLD = 2.0;   // below this, RPM is reported as 0
const int   NUM_SAMPLES   = 5;     // moving-average window
```

Encoder jitter makes a stationary wheel report small non-zero RPM. Watch the
reported RPM with the cart at rest and set `RPM_THRESHOLD` just above the
observed noise. Raising `NUM_SAMPLES` smooths the signal but adds lag — at 60 Hz
sampling, 5 samples is about 83 ms of averaging.

## Calibration record

Fill this in for your build so the numbers are not lost between sessions.

| Constant | V1 default | Your value | Date | Notes |
|---|---|---|---|---|
| `WHEEL_DIAMETER_M` | 0.065 | | | Measure the assembled wheel |
| `CALIBRATION_FACTOR` | −33.0 | | | |
| `FORCE_OFFSET` | 5396.799 | | | Consider 0.0 |
| `ACCEL_X_OFFSET` | 0.0 | | | |
| `ACCEL_Y_OFFSET` | 0.0 | | | |
| `GYRO_X_OFFSET` | 0.0 | | | |
| `GYRO_Y_OFFSET` | 0.0 | | | |
| `GYRO_Z_OFFSET` | 0.0 | | | |
| `RPM_THRESHOLD` | 2.0 | | | |

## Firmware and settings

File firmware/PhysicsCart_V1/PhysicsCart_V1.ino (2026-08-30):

// ════════════════════════
// Physics Cart V1 — Complete Firmware
// Sensors: MPU-6050, HX711, AS5600
// Output:  Bluetooth BLE + Serial Monitor
// ════════════════════════

#include <Wire.h>
#include <HX711.h>
#include <AS5600.h>
#include <BLEDevice.h>
#include <BLEServer.h>
#include <BLEUtils.h>
#include <BLE2902.h>

// ── Pin Definitions ──
#define HX711_DOUT  19
#define HX711_SCK   18
const int MPU_ADDR = 0x68;

// ── Calibration Constants (update after calibrating) ──
const float CALIBRATION_FACTOR  = -33.0;     // raw units per gram
const float FORCE_OFFSET        = 5396.799;  // zero offset (N)
const float GRAVITY             = 9.81;
const float WHEEL_DIAMETER_M    = 0.065;     // measure your wheel (m)
const float WHEEL_CIRCUMFERENCE = WHEEL_DIAMETER_M * 3.14159;
const float RPM_THRESHOLD       = 2.0;       // below this = stopped
const int   NUM_SAMPLES         = 5;         // RPM averaging window

const float ACCEL_X_OFFSET = 0.0;
const float ACCEL_Y_OFFSET = 0.0;
const float GYRO_X_OFFSET  = 0.0;
const float GYRO_Y_OFFSET  = 0.0;
const float GYRO_Z_OFFSET  = 0.0;

// ── BLE UUIDs ──
#define SERVICE_UUID        "4fafc201-1fb5-459e-8fcc-c5c9c331914b"
#define CHARACTERISTIC_UUID "beb5483e-36e1-4688-b7f5-ea07361b26a8"

BLECharacteristic *pCharacteristic;
BLEServer         *pServer;
bool deviceConnected = false;
bool wasConnected    = false;

class MyCallbacks : public BLEServerCallbacks {
  void onConnect(BLEServer *pServer)    { deviceConnected = true; }
  void onDisconnect(BLEServer *pServer) { deviceConnected = false; }
};

const unsigned long SENSOR_INTERVAL_US = 16667; // 60Hz
const unsigned long BLE_INTERVAL_MS    = 50;    // 20Hz
unsigned long lastSensorUpdate = 0;
unsigned long lastBLEUpdate    = 0;
unsigned long startTime;

HX711  scale;
AS5600 encoder;
float rpmSamples[NUM_SAMPLES] = {0};
int   sampleIndex = 0;

float accelX, accelY, accelZ;
float gyroX, gyroY, gyroZ;
float lastNewtons = 0;
float angle, rpm, velocity, seconds;

void setup() {
  Wire.begin(21, 22);
  Wire.setClock(400000);
  delay(1000);
  Wire.beginTransmission(MPU_ADDR);
  Wire.write(0x6B); Wire.write(0);
  Wire.endTransmission(true);
  scale.begin(HX711_DOUT, HX711_SCK);
  delay(2000);
  if (scale.is_ready()) { scale.set_scale(CALIBRATION_FACTOR); scale.tare(20); }
  encoder.begin(4);
  BLEDevice::init("PASCO_Cart");   // matches the Physics Cart App
  pServer = BLEDevice::createServer();
  pServer->setCallbacks(new MyCallbacks());
  BLEService *pService = pServer->createService(SERVICE_UUID);
  pCharacteristic = pService->createCharacteristic(
    CHARACTERISTIC_UUID,
    BLECharacteristic::PROPERTY_READ | BLECharacteristic::PROPERTY_NOTIFY);
  pCharacteristic->addDescriptor(new BLE2902());
  pService->start();
  BLEAdvertising *pAdv = pServer->getAdvertising();
  pAdv->addServiceUUID(SERVICE_UUID);
  pAdv->setScanResponse(true);
  pAdv->setMinPreferred(0x06);
  pAdv->start();
  startTime = millis();
}

void readSensors() {
  Wire.beginTransmission(MPU_ADDR);
  Wire.write(0x3B); Wire.endTransmission(false);
  Wire.requestFrom(MPU_ADDR, 14, true);
  int16_t ax = Wire.read() << 8 | Wire.read();
  int16_t ay = Wire.read() << 8 | Wire.read();
  int16_t az = Wire.read() << 8 | Wire.read();
  Wire.read(); Wire.read();
  int16_t gx = Wire.read() << 8 | Wire.read();
  int16_t gy = Wire.read() << 8 | Wire.read();
  int16_t gz = Wire.read() << 8 | Wire.read();
  accelX = (ax / 16384.0) - ACCEL_X_OFFSET;
  accelY = (ay / 16384.0) - ACCEL_Y_OFFSET;
  accelZ =  az / 16384.0;
  gyroX  = (gx / 131.0) - GYRO_X_OFFSET;
  gyroY  = (gy / 131.0) - GYRO_Y_OFFSET;
  gyroZ  = (gz / 131.0) - GYRO_Z_OFFSET;
  if (scale.is_ready()) {
    float grams = scale.get_units(1);
    lastNewtons = (grams / 1000.0 * GRAVITY) + FORCE_OFFSET;
  }
  angle = encoder.readAngle() * 0.0879;
  float rawRPM = encoder.getAngularSpeed();
  rpmSamples[sampleIndex] = rawRPM;
  sampleIndex = (sampleIndex + 1) % NUM_SAMPLES;
  float avgRPM = 0;
  for (int i = 0; i < NUM_SAMPLES; i++) avgRPM += rpmSamples[i];
  avgRPM /= NUM_SAMPLES;
  rpm      = (abs(avgRPM) < RPM_THRESHOLD) ? 0.0 : avgRPM;
  velocity = (rpm / 60.0) * WHEEL_CIRCUMFERENCE;
  seconds  = (millis() - startTime) / 1000.0;
}

void loop() {
  if (!deviceConnected && wasConnected) {
    delay(500); pServer->getAdvertising()->start(); wasConnected = false;
  }
  if (deviceConnected) wasConnected = true;
  unsigned long nowUS = micros(), nowMS = millis();
  if (nowUS - lastSensorUpdate >= SENSOR_INTERVAL_US) {
    lastSensorUpdate = nowUS; readSensors();
  }
  if (deviceConnected && (nowMS - lastBLEUpdate >= BLE_INTERVAL_MS)) {
    lastBLEUpdate = nowMS;
    char json[220];
    snprintf(json, sizeof(json),
      "{\"t\":%.2f,\"ax\":%.3f,\"ay\":%.3f,\"az\":%.3f,\"gx\":%.1f,\"gy\":%.1f,\"gz\":%.1f,\"f\":%.3f,\"a\":%.1f,\"r\":%.1f,\"v\":%.3f}",
      seconds, accelX, accelY, accelZ, gyroX, gyroY, gyroZ,
      lastNewtons, angle, rpm, velocity);
    pCharacteristic->setValue(json);
    pCharacteristic->notify();
  }
}

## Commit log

2026-08-30 Add Smart Cart V1: firmware, 3D-printable parts, and docs
    First complete version of the instrumented physics cart.
    Firmware (firmware/PhysicsCart_V1/): ESP32 sketch reading MPU-6050,
    HX711 load cell, and AS5600 encoder, streaming JSON over BLE at 20 Hz
    with 60 Hz sensor sampling.
    Hardware (hardware/stl/): four printable parts built around 8 mm bore
    bearings — chassis, wheel, bearing casing, and axle — all named V1.
    Docs (docs/): pinout and sensor connections, a calibration procedure
    covering every tunable constant, and the BLE service/payload spec.
    Known V1 issues are recorded in the README rather than patched, so the
    code here matches the cart as actually built: WHEEL_DIAMETER_M is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
    [Axle_8mm_V1.stl, Bearing_Casing_8mm_V1.stl, Cart_Casing_8mm_Bearing_V1.stl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]
2026-08-31 Add Smart Cart Lab: browser physics simulation for labs
    A self-contained 3D simulation (simulation/index.html) of the V1 cart:
    modified-Atwood hanging mass, inclined track, fan force, static/kinetic
    friction and spring-bumper collisions, integrated at 240 Hz. The sensor
    pipeline mirrors the firmware — 60 Hz sampling, 20 Hz BLE-format JSON
    stream, 5-sample RPM average with 2 RPM cutoff, IMU reporting specific
    force in g, 34 mm wheel — with live velocity/acceleration/force charts,
    readout tiles, sensor-noise toggle and CSV export. Three.js r128 is
    vendored so the app runs offline in a lab.
    Claude-Session: https://claude.ai/code/sessio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
2026-08-31 Make track length adjustable (0.6-2.0 m)
    New Track length slider. Physics bounds, the far end-stop, levelling
    feet, table size, start-position slider range and camera framing all
    follow the chosen length; changing it mid-run restarts the experiment,
    like swapping the physical track. The fan-cart preset now uses the
    full 2 m track.
    Claude-Session: https://claude.ai/code/session_01Cjnu12mGB59BoubPXChxjT
2026-08-31 Add a Reset values button
    Restores the selected preset's slider values, or the app defaults when
    on a custom setup; also re-enables sensor noise. Distinct from Reset,
    which only rewinds the run.
    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
2026-08-31 Add Cart Blanche: physics adventure game with missions, PVE and shop
    A single-file 3D game (game/index.html) built on the Smart Cart theme:
    20 missions across 4 physics worlds, kinetic-energy ram combat with a
    live KE readout, question gates drawing on 48 verified physics
    questions, coins/XP/levels, and an upgrade shop (motor, wheels,
    battery, shield, magnet, liveries). The 120 Hz engine does honest
    slope dynamics with rolling friction, drag, mud/ice zones and
    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
    [LargeBuilding01.obj, SmallBuilding03.obj, SmallBuilding04.obj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]
2026-08-31 Add walkable campus hub, Overvolt streak and LETHAL indicator
    The game now opens onto a large walkable campus: a third-person
    character on foot (WASD/joystick, Shift to run, E to interact) with
    Newt following behind, KayKit roads crossing a plaza, four district
    portals that launch each world's missions, NPCs with dialogue,
    Millie Volt's shop as an enterable building, and one-time collectible
    coins persisted in the save. Cosmetic purchases now swap and tint the
    follower cart live.
    In missions: correct first-try gate answers stack an Overvolt thrust
    bonus (+1 N each, max +3, reset on a miss), and the HUD energy readout
    glows LETHAL when current KE beats a nearby enemy's threshold.
    Co-Authore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
    [road_junction.obj, road_straight.obj, road_straight_crossing.obj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]
2026-09-02 Add The Physics Company: AP Physics 1 lab-career game
    A new labsim/ app built on the Smart Cart simulation. Students are
    hired by The Physics Company to certify the SC-01 through six
    in-depth labs (kinematics, dynamics/friction, energy, momentum, SHM,
    rotation), running real 240 Hz experiments and typing numeric answers
    with units that are graded against their own recorded telemetry
    (+-4%, pay decays 100/70/40% with hints and worked solutions).
    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
    [MountainRocks-1.obj, MountainRocks-3.obj, MountainRocks-5.obj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]
2026-09-02 The Physics Company: city intro, walkable lab, bench setup, Fluids lab, day cycle
    - Title screen now sits over a living city street (KayKit City Bits) with
    traffic, pedestrians and the TPC building; division chips + news ticker.
    - Cinematic skippable intro: drive in, park, walk into the Field Test
    Division; letterboxed with subtitles.
    - HQ is now a walkable lab floor (WASD/click + E): test bench, workshop
    desk, mail terminal, equipment wall, records desk, the Deep End tank,
    Engineer #7's taped-off desk, a cot, whiteboard and window street view.
    - PC-Building-Simulator-style bench setup: parts tray + glowing slots per
    lab; Lab 01 boost is now a pulley + hanging-mass drive.
    - New Lab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
    [bench.obj, book_case.obj, building_A.obj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]
2026-09-02 Bench orbit camera, founder hiring scene, tutorial, de-pixelated look, fixes
    - Lab camera is now orbitable: drag to look, scroll to zoom; during bench
    setup it frames the whole track clear of the UI panels (fixes the
    unplaceable pulley), and the telemetry panel hides until setup is done.
    - Right-click removes a placed part back to the tray; oversized invisible
    hit volumes make every slot easy to click.
    - Procedure list rebuilt: one stable line per part + per run, no more
    aggregate line that appeared to uncheck on mode switches.
    - Guided 6-step tutorial bar for Lab 01.
    - New hiring scene: after the drive-in, R. Fulcrum (Founder & Owner)
    explains the company over click-through dialog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
    [deskmat.obj, lamp_architect.obj, monitor_ultrawide.obj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]
2026-09-02 Rebuild lab scene as track-on-a-bench, real humanoid character, TPC-OS terminal UI
    - Lab view remade from scratch in the original simulator's style: a long
    steel lab bench carries the rail track (lips, metre ticks, levelling
    legs) inside a dark lab room with glowing windows, hanging fixtures and
    a grid floor; no more prototype-block terrain or colored marker cubes.
    Incline labs get a scissor riser; the outdoor range is now a grass
    field with low-poly conifers, hazed distant mountains and a stone
    geothermal vent; the Deep End tank sits properly on the bench.
    - Characters are now the user-provided Base Humanoid Mesh: extracted from
    Humanoid.fbx by a new binary-FBX parser, split i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
    [h_armL.obj, h_armR.obj, h_head.obj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]
2026-09-02 Fix humanoid arms clipping through the body
    Re-rig each arm as two nested groups: the outer group swings about x for
    the walk cycle, the inner group holds the constant T-pose-to-rest shoulder
    drop about z. The previous single-Euler composition twisted the swing into
    the torso. Shoulders also seated slightly outboard and arm swing amplitude
    reduced.
    Claude-Session: https://claude.ai/code/session_016zoEABcVppapxwM1Eu3AJK
2026-09-02 Worksheet questions only reference rows that exist in the student's table
    - Lab 01's cruise question picks its interval endpoints from the student's
    own recorded run (last 0.5 s table row), instead of a fixed t = 6.0 s
    that short fast runs never reach; the t = 3.0 s velocity question is now
    worded explicitly as a prediction.
    - Every lab's required-run checks now verify the data its worksheet reads
    actually got recorded: minimum durations (L1 cruise/boost, L2 release,
    L6 roll to 3 s), and required events (L3 past-the-gravel velocities,
    L4 impulse/collision events, L5 five zero crossings) — a run stopped
    early no longer counts and can no longer produce unanswerable questions.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
2026-09-02 Worksheet: refresh questions from the latest recorded runs
    The worksheet used to be generated once and cached, so re-running a pass
    left the questions quoting stale values that no longer matched the data
    table. Now the questions are rebuilt from the newest matching runs every
    time the worksheet opens, and a '⟳ Use latest runs' button in the
    worksheet header rebuilds them on demand. Answered questions stay
    answered; attempts and pay tiers persist across refreshes.
    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
2026-09-02 Add a Skip (testing) button to worksheet questions
    Marks the current question complete for $0 pay so testers can move
    through worksheets quickly. Attempts/score bookkeeping unchanged; the
    skipped flag is stored on the question state.
    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
2026-09-02 Lab 2 tilt rig rebuilt + adjustable start angle + mission briefings
    - The incline track now hinges at its downhill end (which rests on the
    bench, with a visible hinge barrel) while a scissor riser jacks the
    start end up above the bench — the rail no longer plunges through the
    table and the stand sits under the raised end where it belongs. The
    camera lifts with the cart on inclines.
    - Tilt test gains a Start angle slider (0-15°) that previews the tilt
    live before running; the motorized creep then continues from there.
    The required tilt run must begin at least 1° below the slip angle so
    the measurement stays honest.
    - Every lab now opens with a mission briefing popup: THE IDE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
2026-09-02 Lab 2: live angle gauge, tab hints on the checklist, friendlier placement
    - The angle gauge is now a real instrument: protractor disc, baseline,
    orange needle tracking the track angle, and a large live degree
    readout (canvas sprite rewritten as the angle changes) — visible in
    both tilt and release modes, placed by the riser where the camera
    looks.
    - Procedure lines on multi-mode labs now name the tab each run belongs
    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
2026-09-02 Polish hub: socket shoulders, clear cot corner, fix chair facing
    - Re-socket the arm pivots into the torso (rest drop 0.9 rad, arms
    nudged inward/up) so the shoulders read as one combined model
    - Remove the whiteboard and the records desk + transcript printer near
    the cot; the transcript stays available in the terminal's CertViewer
    - Remove the wall-mounted cabinet shelf that clipped through the wall;
    spring, masses and sensor crates now sit on the floor cabinets
    - Flip the bench, mail, workshop and founder-office chairs to face
    their tables
    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
2026-09-02 Smooth hair geometry + dev build flag with full catalog unlocked
    - Replace the box hair cap with a smooth-shaded sphere dome + back-of-
    head mass, so the hair no longer reads as a pixelated block
    - Add a DEV flag (window.PHYSCO_DEV or a #dev URL hash) that unlocks
    every lab, sensor, shell, LED, extra and office item, grants $9999,
    plays on a separate save slot, and shows a DEV BUILD badge
    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
2026-09-03 Jointed walk cycle, dev mode, lab room windows/sign/steel bench, cart textures
    - Split each limb mesh at the knee/elbow at load time (joint spheres hide
    the seam) so knees fold in swing and elbows hold a natural bend
    - Hair dome moved forward; floor caution strip under the bench chair
    removed; coffee-corner mug now sits on a second cabinet
    - Lab 02 release mode: the cart rolls off the ramp onto the bench and
    skids to rest instead of passing through the table
    - Dev mode: title-screen entry plus a testing panel (lab jump, certify,
    money, sleep cutscene, reset) in DEV builds; all labs unlocked there
    - Lab room: real windows (frames, glass, piers) looking onto a street
    with buildings a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
2026-09-03 Body choice, black hair, hidden joint fillers, wall-mounted sign, tank winch, coil springs, ramp pose
    - Hire screen offers Female / Male; the player model uses it (shoulder
    width, height, long hair with ponytail vs short) with black hair
    - Knee/elbow fillers are ellipsoids sized to each limb's cross-section
    and arms hang straight at rest, so no balls show on the joints
    - Lab sign is a framed plate on standoff pegs in front of the wall
    - Lab 07: winch pays out from t=0 at 0.04 m/s from a lower rest height,
    drum turns, cylinder settles with a damped swing in the weigh pass;
    the tank label moves onto the glass, clear of the sign
    - Labs 04/05 springs are real helical coils (TubeGeometry)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
